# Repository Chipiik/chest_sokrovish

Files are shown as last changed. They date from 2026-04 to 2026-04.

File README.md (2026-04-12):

# 📦 ПРОЕКТ "СУНДУК СОКРОВИЩ" - Биоуправление для коррекции внимания (СДВГ)

## 🎯 Описание проекта

Устройство для тренинга биоуправления, предназначенное для коррекции нарушений внимания (СДВГ) у детей и подростков.

### Задачи устройства:

**Часть 1: Управление крышкой по ЭМГ (мышцы лба)**
- Удерживать ЭМГ ниже порога 3 минуты → крышка открывается (0° → 90°)
- Если ЭМГ выше порога → крышка закрывается в 2 раза быстрее
- Сглаживание сигнала скользящим средним (500 мс)

**Часть 2: Детекция бета-ритма ЭЭГ (13-18 Гц)**
- Если бета-ритм > порога ≥60% времени → зажечь светодиоды ("драгоценные камни")
- Периоды с высоким ЭМГ не засчитываются

---

## 📁 Структура проекта

```
treasure-chest/
├── README.md                    # Этот файл
├── docs/
│   ├── hardware/                # Документация по оборудованию
│   │   └── connection-schema.md # Схема подключения
│   ├── software/                # Документация ПО
│   │   └── bitronics-setup.md   # Настройка Bitronics Lab
│   └── user-guides/             # Руководства пользователя
│       └── quick-start.md       # Быстрый старт
├── src/
│   ├── main/                    # Основная программа с датчиками
│   │   └── treasure_chest.ino
│   └── test/                    # Тестовая программа с эмуляцией
│       └── treasure_chest_test.ino
├── libraries/                   # Библиотеки (при необходимости)
└── !docs/                       # Исходные документы (не изменять)
```

---

## 🔌 Оборудование

### Необходимые компоненты:

| Компонент | Модель | Количество |
|---|---|---|
| Плата Arduino | Arduino Mega 2560 | 1 |
| LED индикатор | Grove LED Bar v1.0 (MY9221) | 1 |
| Сервопривод | FS5103B | 1 |
| Датчик ЭЭГ | Bitronics Lab EEG | 1 |
| Датчик ЭМГ | Bitronics Lab EMG/ECG | 1 |
| Кабели | Grove/Jumper wires | несколько |

### Требуемые библиотеки Arduino:

1. **Grove_LED_Bar** (Seeed Studio) - установка через Library Manager
2. **Servo** (встроена в Arduino IDE)
3. **arduinoFFT** (Enrique Condes) - только для основной версии

---

## 🚀 Быстрый старт

### Вариант 1: Тестирование БЕЗ датчиков (рекомендуется!)

1. **Подключите:**
   - Grove LED Bar к пинам 2, 3
   - Сервопривод к пину 9
   - Arduino к компьютеру через USB

2. **Загрузите:** `src/test/treasure_chest_test.ino`

3. **Откройте Serial Monitor** (115200 бод)

4. **Введите команды:**
   ```
   HELP         ← Получить справку
   AUTO         ← Автоматический режим
   STATUS       ← Показать статус
   SUCCESS      ← Симуляция успеха
   FAIL_EMG     ← Провал по мышцам
   FAIL_EEG     ← Провал по ЭЭГ
   RESET        ← Перезапустить
   ```

### Вариант 2: Работа с реальными датчиками

1. **Подключите все компоненты** по схеме в `docs/hardware/connection-schema.md`

2. **Разместите электроды:**
   - **ЭМГ:** над левой и правой бровью (2 см выше)
   - **ЭЭГ:** Fpz (над переносицей) + за ухом (референт)

3. **Загрузите:** `src/main/treasure_chest.ino`

4. **Откройте Bitronics Lab** или Serial Monitor (112500 бод)

5. **Нажмите RESET** на Arduino

6. **Пройдите калибровку** (30 секунд):
   - Сидите спокойно
   - Лицо расслаблено
   - Глаза открыты

7. **Выполните тренинг** (3 минуты):
   - Расслабьте лоб → крышка открывается
   - Решайте арифметические задачи → бета-ритм растёт

---

## 📊 Критерии успеха

| Условие | Требование | Индикация |
|---|---|---|
| **Крышка** | Открыта ≥54° (60% от 90°) | LED Bar показывает угол |
| **Бета-ритм** | > порога ≥60% времени | Зелёные светодиоды |
| **Общий успех** | Оба условия выполнены | Все светодиоды горят, зелёные мигают 5 раз |
| **Неудача** | Хотя бы одно не выполнено | Красные светодиоды мигают 3 раза |

---

## ⚙️ Настройка параметров

В начале кода можно изменить:

```cpp
// Время тренинга
const unsigned long TIME_TRAINING = 180000; // 3 минуты

// Коэффициенты порогов (1.2 = легче, 1.5 = сложнее)
const float EMG_THRESHOLD_K = 1.3;
const float BETA_THRESHOLD_K = 0.7;

// Процент успеха для бета-ритма
const float BETA_SUCCESS_RATIO = 0.6; // 60%

// Диапазон бета-ритма
const float BETA_FREQ_LOW = 13.0;    // Подростки: 13-18 Гц
const float BETA_FREQ_HIGH = 18.0;
// const float BETA_FREQ_LOW = 12.0;  // Дети: 12-15 Гц

// Скорости серво
const float LID_SPEED_OPEN = 0.15;   // Медленное открытие
const float LID_SPEED_CLOSE = 0.30;  // Быстрое закрытие (×2)
```

---

## 🔋 Автономная работа

**Устройство может работать без компьютера!**

### Что нужно:
- Power Bank 5V 2A (или батарейный отсек 4xAA)
- Подключить к USB порту Arduino или к Vin+GND

### Как работает:
1. Загрузите `src/main/treasure_chest.ino`
2. Подключите все датчики
3. Подайте питание от Power Bank
4. Нажмите RESET
5. Устройство автоматически проведёт калибровку и тренинг

### Индикация результата:
- ✅ **УСПЕХ:** Все 10 светодиодов горят, зелёные мигают 5 раз
- ❌ **НЕУДАЧА:** Красные светодиоды мигают 3 раза

---

## 🐛 Диагностика проблем

| Проблема | Решение |
|---|---|
| Серво дёргается | Отдельное питание 5V 1A+, увеличить SERVO_INTERVAL до 300 |
| Крышка не открывается | Уменьшить EMG_THRESHOLD_K до 1.2, проверить контакт электродов |
| LED Bar не светится | Проверить подключение D1→2, D2→3, установить библиотеку |
| Шум на сигналах | Обезжирить кожу, использовать гель, проверить заземление |
| Всегда неудача | Провести тренировочные сеансы, уменьшить пороги |

---

## ⚡ Техника безопасности

1. ⚠️ **Не подключайте датчики к сети 220V!**
2. ⚠️ **Используйте только питание 5V от USB или батареек**
3. ⚠️ **Проверьте изоляцию проводов перед использованием**
4. ⚠️ **Не используйте на людях с эпилепсией без консультации врача**
5. ⚠️ **При дискомфорте немедленно прекратите сеанс**

---

## 📚 Дополнительная документация

Подробная информация доступна в папке `docs/`:

- `docs/hardware/connection-schema.md` - Подробная схема подключения
- `docs/software/bitronics-setup.md` - Настройка Bitronics Lab
- `docs/user-guides/quick-start.md` - Пошаговое руководство для начинающих

Исходные документы в папке `!docs/` (не изменять):
- Инженерная книга
- Паспорт устройства
- Руководство пользователя BiTronics

---

## 👥 Авторы

Проект разработан для конкурса инженерных книг.

**Лицензия:** Образовательный проект

---

**УДАЧИ В РЕАЛИЗАЦИИ ПРОЕКТА! 🎉**

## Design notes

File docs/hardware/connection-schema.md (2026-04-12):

# 🔌 Схема подключения оборудования

## Общий вид системы

```
                    ┌─────────────────┐
                    │   ARDUINO MEGA  │
                    │                 │
     ЭМГ датчик ────┤ A1          D2  ├──── Grove LED Bar
     (лоб)          │             D3  │      (10 светодиодов)
                    │             D9  ├──── Сервопривод
     ЭЭГ датчик ────┤ A0              │      (крышка сундука)
     (Fpz/Fz)       │           5V/GND├──── Питание
                    │                 │
     Компьютер ─────┤ USB         GND ├──── Общая земля
                    └─────────────────┘
```

---

## 🔌 Подключение к Arduino Mega

### 1. Grove LED Bar v1.0 (MY9221)

| Провод LED Bar | Цвет провода | Пин Arduino Mega | Примечание |
|---|---|---|---|
| GND | Чёрный | GND | Земля |
| VCC | Красный | 5V | Питание 5В |
| D1 (DIN/DATA)  | Белый | **Digital 2** | Данные |
| D2 (CLK) | Жёлтый | **Digital 3** | Тактирование |

**Важно:** 
- Модуль потребляет ~40mA при всех включенных светодиодах
- Можно питать от 5V Arduino

---

### 2. Сервопривод FS5103B

| Провод серво | Цвет | Пин Arduino Mega | Примечание |
|---|---|---|---|
| GND | Коричневый/Чёрный | GND | Земля |
| VCC | Красный | **5V** | Питание |
| SIGNAL | Оранжевый/Жёлтый | **Digital 9**  | PWM сигнал |

**⚠️ ВНИМАНИЕ:**
- Сервопривод в пиковом режиме потребляет до 500mA!
- При проблемах (дёргания, перезагрузки) используйте **отдельное питание 5V 1A**
- Подключите конденсатор 470-1000 мкФ между VCC и GND серво

**Схема с отдельным питанием:**
```
Power Bank 5V ──┬── VCC серво (красный)
                │
                └── Vin Arduino (если нужно)
                
GND Power Bank ─┬── GND серво (коричневый)
                │
                └── GND Arduino (общая земля!)
```

---

### 3. Датчик ЭМГ/ЭКГ Bitronics Lab

| Пин модуля | Обозначение | Пин Arduino Mega | Примечание |
|---|---|---|---|
| GND (-) | Земля | GND | Чёрный провод |
| VCC (+) | Питание | 5V | Красный провод |
| OUT | Сигнал | **Analog A1** | Белый провод |

**Настройка усиления (Gain):**
- На модуле есть потенциометр для настройки усиления
- Начальное положение: среднее
- Для лба: усилить больше (по часовой стрелке)
- Для бицепса: меньше (против часовой)

---

### 4. Датчик ЭЭГ Bitronics Lab

| Пин модуля | Обозначение | Пин Arduino Mega | Примечание |
|---|---|---|---|
| GND (-) | Земля | GND | Чёрный провод |
| VCC (+) | Питание | 5V | Красный провод |
| OUT | Сигнал | **Analog A0** | Белый провод |

**Настройка:**
- Потенциометр Gain выкрутить ближе к максимуму
- ЭЭГ сигнал очень слабый (микровольты)

---

## 👤 Размещение электродов на теле

### Для ЭМГ (мышцы лба):

**Вариант 1 - Лоб (рекомендуется):**
```
        ┌───────────────┐
        │   Электрод 1  │  ← Над левой бровью (2 см выше)
        │       •       │
        │               │
        │   Электрод 2  │  ← Над правой бровью (2 см выше)
        │       •       │
        │               │
        │   Земля       │  ← На виске или за ухом
        │       •       │
        └───────────────┘
```

**Параметры:**
- Расстояние между электродами: 2-3 см
- Обезжирьте кожу спиртом перед наклеиванием
- Используйте гель для ЭКГ для лучшего контакта

---

### Для ЭЭГ (бета-ритм):

**Система координат 10-20:**
```
        Нос
         ↑
    Fpz ─┼─ Fz ─ Cz ─ Pz ─ Oz
    (•)  │  (•)  (•)  
         │   
    ─────┴───── Уши
         │
      Референт (за ухом)
```

**Вариант 1 - Fpz (монополярно, рекомендуется):**
- Активный электрод: над переносицей (Fpz)
  - Отступите ~10% от переносицы вверх по лбу
- Референтный: за правым или левым ухом (сосцевидный отросток)
- Земля: на лбу справа или слева

**Важно:**
- Зачешите волосы в стороны от места крепления
- Используйте специальный гель для ЭЭГ
- Зафиксируйте электроды шапочкой или повязкой

---

## 📦 Установка библиотек

### В Arduino IDE:

1. Откройте **Arduino IDE**
2. Перейдите: **Скетч → Подключить библиотеку → Управлять библиотеками...**
3. Найдите и установите:

| Библиотека | Автор | Версия | Назначение |
|---|---|---|---|
| `Grove LED Bar` | Seeed Studio | ≥2.0.0 | Управление LED баром |
| `Servo` | Arduino | Встроена | Управление серво |
| `arduinoFFT` | Enrique Condes | ≥1.5.6 | БПФ для ЭЭГ (только для основной версии) |

**Для тестовой версии (`treasure_chest_test.ino`) библиотека arduinoFFT НЕ нужна!**

---

## 📊 Таблица пинов Arduino Mega

| Компонент | Пин | Тип | Направление |
|---|-----|-----|---|
| Grove LED Bar DATA | 2 | Digital | Выход |
| Grove LED Bar CLK | 3 | Digital | Выход |
| Сервопривод SIGNAL | 9 | PWM | Выход |
| Датчик ЭЭГ OUT | A0 | Analog | Вход |
| Датчик ЭМГ OUT | A1 | Analog | Вход |
| Все GND | GND | - | Общий |
| Все VCC | 5V | Power | Питание |

**Свободные пины для расширения:**
- Digital: 4-8, 10-13, 14-53
- Analog: A2-A15

---

## ⚡ Техника безопасности

1. **Не подключайте датчики к сети 220V!**
2. **Используйте только питание 5V от USB или батареек**
3. **Перед надеванием электродов проверьте изоляцию проводов**
4. **Не используйте устройство на людях с эпилепсией без консультации врача**
5. **При появлении дискомфорта немедленно прекратите сеанс**

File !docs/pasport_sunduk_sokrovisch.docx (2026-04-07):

Паспорт проекта

Сундук сокровищ

1. Образовательное учреждение: МАОУ Гимназия №7 «Сибирская»
2. Руководитель: Бабаева Елена Александровна
3. Состав команды и роли участников: Бамбурова Дарья Николаевна – нейротехнолог, программист; Куравкин Степан – конструирование.
4. Технические характеристики и область применения.

Для реализации нам потребовались: датчики юниор ЭЭГ и ЭМГ, резистор, светодиод, макетная плата, Arduino Uno, ноутбук с программным обеспечением Arduino, шаговый двигатель и драйвер к нему, соединительные провода, материалы для сундука(дерево).

Мы разработали устройство доступное и

удобное в использовании для тренировки концентрации внимания.

Оно подойдет людям, у которых присутствуют нарушения концентрации внимания.

5. Стоимость реализации.
6. Фотография проекта (или программа).

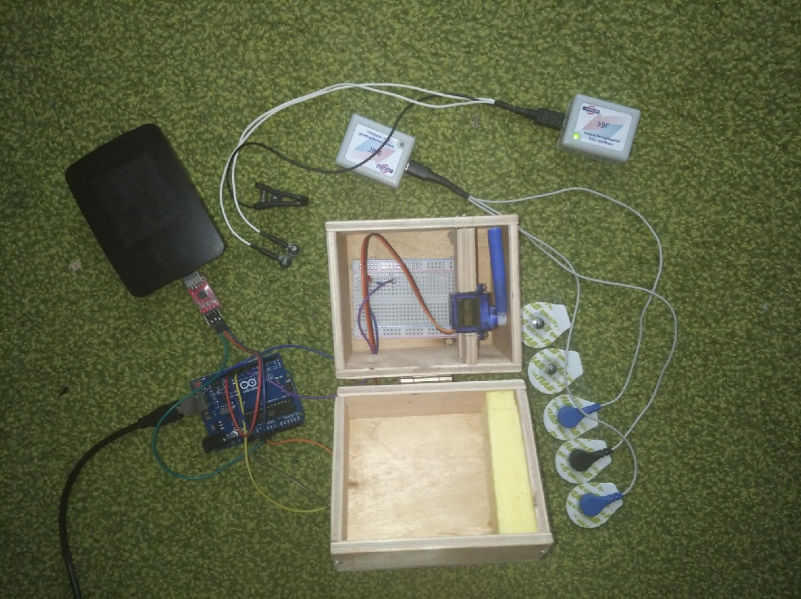
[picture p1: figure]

7. Каталог используемых ресурсов.

Приложение 1. Инженерная книга (отдельным файлом) на 26 страницах.

Приложение 2. Презентация в Power Point (отдельным файлом) на 15 слайдах.

VIII Турнир юных инженеров-исследователей

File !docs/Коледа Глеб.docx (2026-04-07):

Муниципальное автономное общеобразовательное учреждение г. Новосибирска

«Гимназия №7 «Сибирская»

«Умная шкатулка»

Автор:

Коледа Глеб

Руководитель:

Бабаева Елена Александровна

Новосибирск, 2025

Содержание

# Аннотация

Целью моей работы стало создание шкатулки для надежного хранения ценностей, для достижения цели я изучил среду Arduino и разработал конструкцию шкатулки.

Для поиска информации по похожим изобретениям, выполненным на базе Arduino, я использовал ресурсы интернета и профессиональный опыт руководителя.

В ходе работы я написал программу, собрал шкатулку и подключил необходимые приборы. Результатом является работающее устройство, имеющее небольшую стоимость производства. Использование моего продукта актуально для подростков, у которых есть младшие братья или сестры.

# Актуальность

Сейчас многие подростки сталкиваются с ситуацией, когда их младшие братья и сестры берут ценные вещи без спроса, для решения этой проблемы я решил создать уникальную шкатулку, которую невозможно будет открыть без пульта и в которой можно хранить небольшие вещи или копить деньги.

# Цель:

создать умную шкатулку с использованием Arduino .

# Задачи:

1) Изучить аппаратную базу Arduino
2) Изучить программную базу Arduino
3) Освоить работу с ИК-датчиками и сервоприводами
4) Разработать конструкцию и дизайн шкатулки
5) Собрать устройство
6) Провести тесты

Теоретическая часть

Платформа Arduino

Arduino – платформа, с открытым исходным кодом для создания электронных устройств и интерактивных объектов. Состоит из аппаратной и программной части.

Основа аппаратной части – плата с микроконтроллером – маленьким компьютером с собственным процессором, памятью и периферией, на плате также имеются порты ввода/вывода для подключения внешних устройств, разъем питания, USB-порт для загрузки программ и обмена данными с компьютером, кнопка сброса для перезапуска микроконтроллера, индикаторные светодиоды.

Программная часть – Среда разработки Arduino IDE, включает в себя: редактор кода, менеджер библиотек, монитор последовательного порта для обмена данными между платой и компьютером, компилятор для преобразования кода в инструкции для микроконтроллера, загрузчик для передачи программы на плату. Язык программирования представляет собой упрощенную версию С++, адаптированную для микроконтроллеров.

ИК-приемник(IR-receiver) – электронное устройство, обнаруживающее инфракрасное излучение, невидимое для человеческого глаза и декодирующее его в электрические сигналы, передаваемые для интерпретации управляющей схеме устройства

ИК-пульт – электронное устройство, передающее сигналы в инфракрасном диапазоне волн, позволяет управлять электронными устройствами. При нажатии на кнопку, пульт генерирует уникальную последовательность сигналов – код команды, он преобразуется в серию световых импульсов определённой частоты и длительности.

Провода Dupont – компоненты, использующиеся для соединения различных модулей, могут иметь соединения типа «папа-папа», «папа-мама», «мама-мама».

Сервопривод – устройство с электрическим мотором, которое можно повернуть на определенный угол и оставить в этом положении на определенное время. Используется для управления движениями механизмов. Состоит из привода, датчика обратной связи, электронной начинки

Макетная плата – инструмент для быстрого прототипирования электронных схем. Позволяет соединять компоненты схемы без пайки. Состоит из множества отверстий, расположенных в определенном порядке. Горизонтальные линии по краям – силовые шины, обычно использующиеся для подачи питания и земли от Arduino, вертикальные ряды в центральной части связаны между собой и предназначены для установки компонентов.

Кабель ПК-Arduino – это USB кабель для подключения платы к компьютеру, позволяет программировать плату и передавать данные по серийному порту.

Библиотеки Arduino – наборы готовых функций и методов, которые позволяют работать с определенными устройствами, выполняя специфические задачи. Существуют встроенные, дополнительные и зависимые библиотеки.

Светодиод – полупроводниковый прибор, создающий оптическое излучение при пропускании через него электрического тока.

# Практическая часть

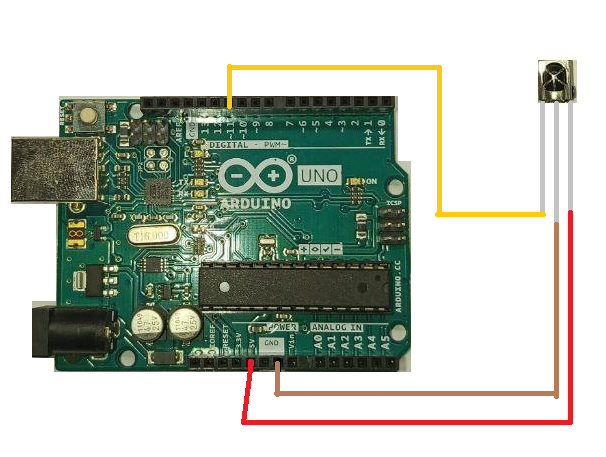
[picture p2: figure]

В своем проекте я использовал плату Arduino UNO, ИК-приемник VS1838B, ИК-пульт, макетную плату, Сервопривод FS5106M, светодиод синий.

## Определение кода

При нажатии на кнопку пульта отправляется код команды, как было сказано выше, для использования пульта необходимо узнать этот код. Для этого воспользуюсь следующей схемой подключения и программой:

Правый контакт приемника подключен к 5V, центральный к GND, левый к пину 11.

#include <IRremote.h>

const int RECV_PIN = 11;

IRrecv irrecv(RECV_PIN);

decode_results results;

void setup() {

Serial.begin(9600);

irrecv.enableIRIn();

}

void loop() {

if (irrecv.decode(&results)) {

Serial.print("Получен код: ");

Serial.println(results.value, HEX);

irrecv.resume(); }

}

В первой стоке загружаю библиотеку IRremote.h (2.6.0) для управления ИК-приемником, далее указываю номер пина, к которому подключен приемник и устанавливаю расшифровку сигнала. В 5-7 строке включаю монитор порта и ИК-приемник. Далее запускаю цикл: если получен сигнал, то в монитор порта выводится результат расшифровки в шестнадцатеричной системе счисления, приемник готовится к получению нового сигнала.

Таким способом определяю код для кнопок «вверх» и «вниз» - FF18E7 и FF4AB5 соответственно.

Основной механизм

После того как я узнал коды кнопок пульта можно приступить к основной части проекта. Собираю следующую схему:

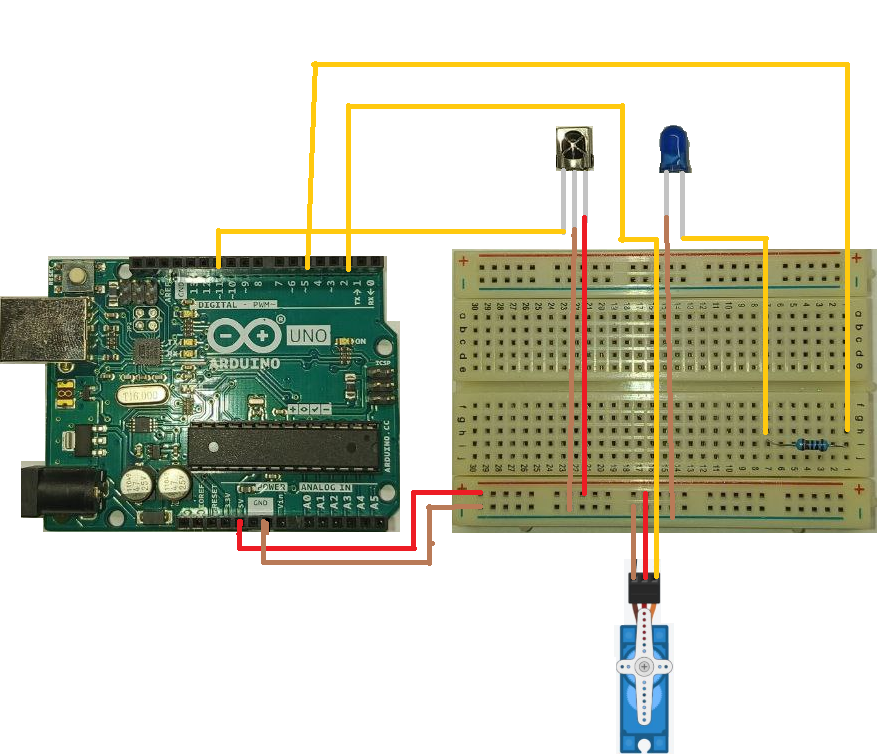
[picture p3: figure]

Приемник подключен к пину 11, светодиод к пину 5, сервомотор к пину 2.

Теперь создаю программу:

#include <IRremote.h>

#include <Servo.h>

#define up 0xFF18E7

#define down 0xFF4AB5

int RECV_PIN = 11;

Servo servo;

IRrecv irrecv(RECV_PIN);

decode_results results;

void setup()

{ Serial.begin(9600);

irrecv.enableIRIn();

servo.attach(2); }

void loop()

{ if (irrecv.decode(&results)) {

Serial.println(results.value, HEX);

irrecv.resume();

}

if (results.value == up)

{ servo.write (90);

digitalWrite(5,HIGH); }

else if (results.value == down) {

servo.write (180);

digitalWrite(5,LOW); }

}

В 1-2 строке подключаю библиотеки для управления сервоприводом и ИК-приемником. В 3-4 строке задаю переменные «up» и «down» через коды пульта.

Далее указываю пин, к которому подключен ИК-приемник, создаю название сервопривода, активирую расшифровку ИК сигнала, монитор порта, ИК-приемник, указываю к какому пину подключен сервопривод.

Использую цикл:

1) если получен сигнал, перевести его в шестнадцатеричную систему, приготовиться к получению следующего сигнала.

2) Если результат декодирования совпадает со значением up, то устанавливается угол сервопривода на 0 градусов и включается светодиод.

3) Если результат декодирования совпадает со значением down, сервопривод устанавливается на 180 градусов и светодиод выключается.

## Установка

В качестве шкатулки использую коробу из фанеры размерами 17х14х13. Крышка утопает внутри коробки так, что ее нельзя открыть руками. Сервомотор размещен на перегородке и при повороте открывает/закрывает крышку. ИК-приемник приклеен к стенке коробки с помощью скотча и принимает сигнал через отверстие. Внутри место для хранения драгоценностей отделено от плат картоном.

# Стоимость

В своем проекте я использовал:

Название компонента | Количество (шт) | Цена (р/шт)* | Стоимость (р)
Плата Arduino UNO | 1 | 634 | 308
ИК-приемник VS1838B | 1 | 38 | 38
ИК-пульт | 1 | 34 | 34
Макетная плата | 1 | 155 | 155
Сервопривод FS5106M | 1 | 252 | 252
Светодиод синий. | 1 | 9 | 9
Коробка | 1 | 449 | 349
Брусок деревянный | 2 | 2,4 | 4,8
Провода «папа-мама» | 5 | 5,3 | 26,3
Провода «папа-папа» | 6 | 3,3 | 19,8
Кабель ПК-Arduino | 1 | 20 | 20
Батарея | 1 | 400 | 400

* - цены взяты с интернет маркетплейсов

Таким образом, стоимость создания моей шкатулки составила 1616 рублей, при стоимости сейфа от 5000 рублей.

# Результат

В ходе проделанной работы я научился работать с устройствами Arduino и создал функционирующую шкатулку, которая открывается с помощью ИК-пульта. Использование моей шкатулки позволяет подросткам спрятать небольшие ценные вещи от младших детей. Стоимость этой шкатулки составляет 1616 рублей

# Ресурсы

Электронные ресурсы:

- [Progoschool - ИК-пульт и Ардуино] - https://progoschool.ru/electronics-for-beginners/ir-remote-control/
- [Arduino+ - Сервопривод Ардуино определение] - https://arduinoplus.ru/arduino-servoprivod/
- [AlexGyvertechnologies - светодиод] - https://alexgyver.ru/lessons/led/
- [Робототехника18 – Как подключить светодиод к Ардуино] - https://роботехника18.рф/светодиод-ардуино/
- [Autodesk Instructables - Controlling Servo Motor Using IR Remote Control] - https://www.instructables.com/Controlling-servo-motor-using-IR-remote-control/

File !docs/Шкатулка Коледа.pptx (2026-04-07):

## Проект "Умная шкатулка"

Выполнил ученик
9Б класса
Коледа Глеб

## Цель и задачи

Цель:
Создать шкатулку с ограниченным доступом
Задачи:
- Изучить аппаратную базу Arduino
- Изучить программную базу Arduino
- Освоить работу с ИК-датчиками и сервоприводами
- Разработать конструкцию и дизайн шкатулки
- Собрать устройство
- Проверить работоспособность устройства

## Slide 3

Среда Arduino

Программная часть

Среда разработки Arduino IDE

Аппаратная часть

Плата
с микроконтроллером

Прочие модули

Редактор кода

Загрузчик

Менеджер библиотек

Монитор порта

## Компоненты

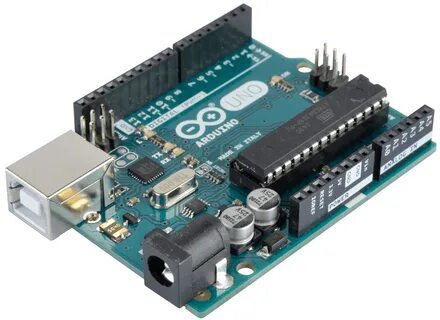
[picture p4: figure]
Изображение выглядит как электроника, Электронный компонент, Компонент схемы, Пассивный компонент цепи Содержимое, созданное искусственным интеллектом, может быть неверным.

Плата с микроконтроллером

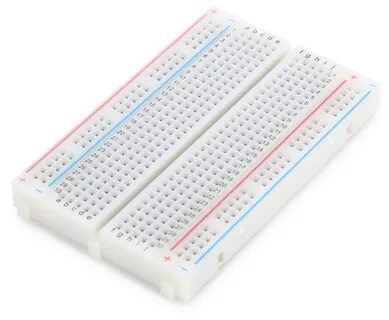
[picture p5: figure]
Изображение выглядит как текст Содержимое, созданное искусственным интеллектом, может быть неверным.
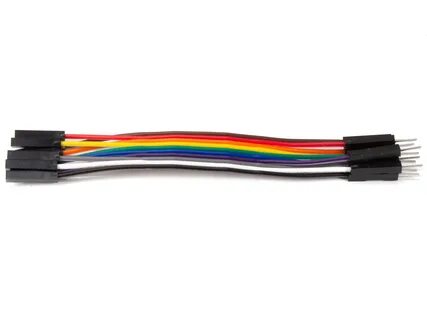
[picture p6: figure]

Макетная плата

Провода "папа-мама"

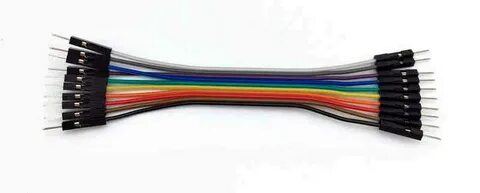
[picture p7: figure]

Провода "папа-папа"

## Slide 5

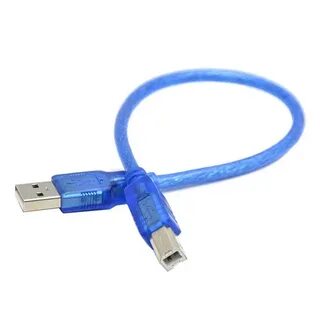
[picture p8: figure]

Кабель ПК-Arduino

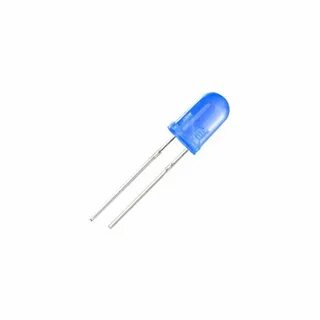
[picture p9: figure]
9 штук, Светодиод 3мм, цв. синий, LED - купить в интернет-магазине по низкой цен

Светодиод

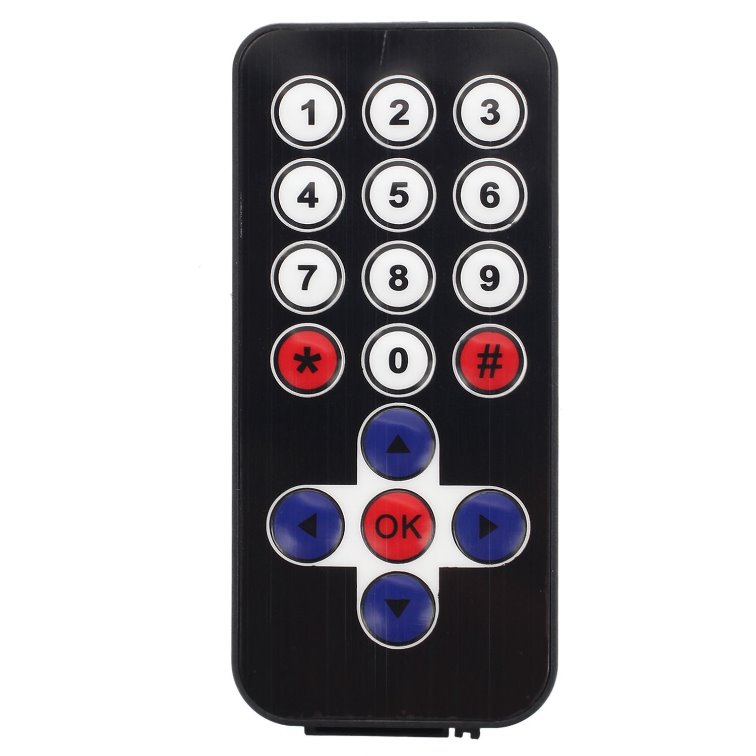
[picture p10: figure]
Picture background

ИК-пульт

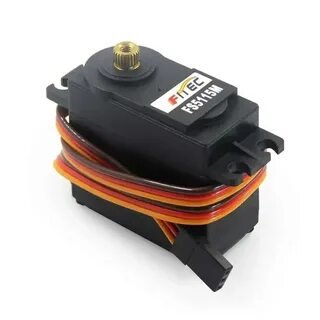
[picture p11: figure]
Серводвигатель Feetech FS5115M 15 кг для робота AliExpress

Сервопривод

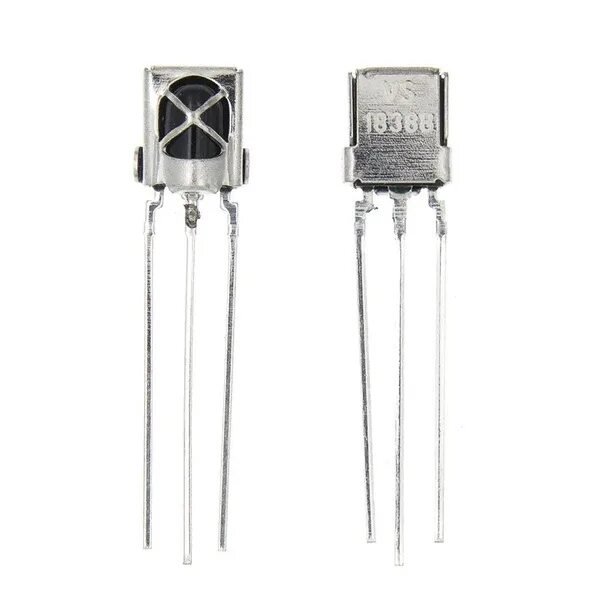
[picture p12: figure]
Picture background

ИК-приемник

## Коды пульта

#include <IRremote.h>

const int RECV_PIN = 11;
IRrecv irrecv(RECV_PIN);
decode_results results;
void setup() {
Serial.begin(9600);
irrecv.enableIRIn(); }
void loop() {
if (irrecv.decode(&results)) {
Serial.print("Получен код: ");
Serial.println(results.value, HEX);
irrecv.resume(); }
}

№ п/п | Кнопка | Код
1 | «вверх» | FF18E7
2 | «вниз» | FF4AB5

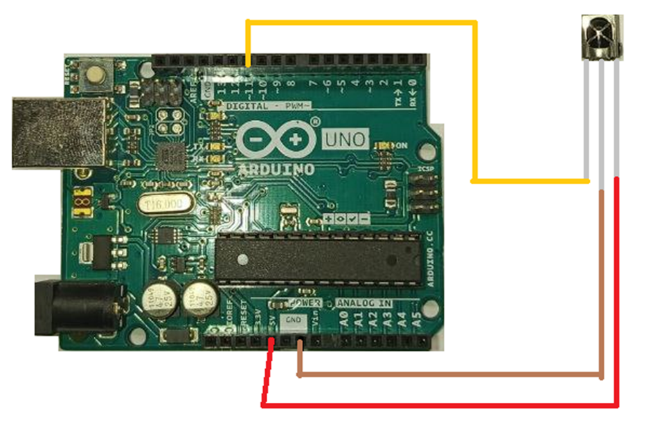
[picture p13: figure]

## Основная часть

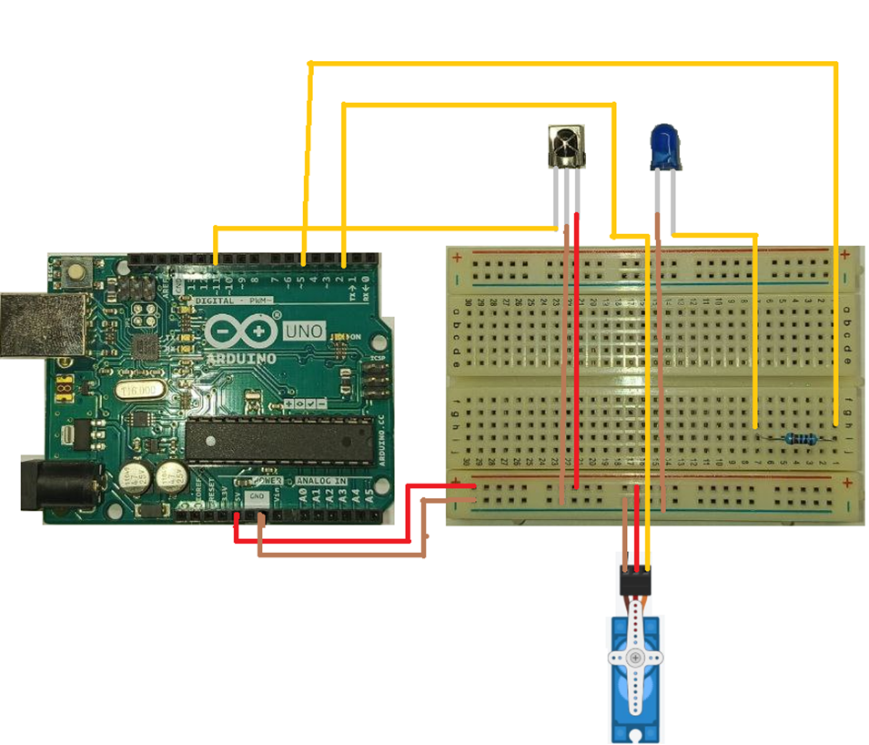
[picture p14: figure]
Изображение выглядит как электроника, Электронный компонент, Компонент схемы, Пассивный компонент цепи Содержимое, созданное искусственным интеллектом, может быть неверным.

#include <IRremote.h>

#include <Servo.h>

#define up 0xFF18E7

#define down 0xFF4AB5

int RECV_PIN = 11;
Servo servo;
IRrecv irrecv(RECV_PIN);
decode_results results; ;
void setup()
{ Serial.begin(9600);
irrecv.enableIRIn();
servo.attach(2); }
void loop()
{ if (irrecv.decode(&results)) {
Serial.println(results.value, HEX);
irrecv.resume();
}
if (results.value == up)
{ servo.write (90);
digitalWrite(5,HIGH); }
else if (results.value == down){
servo.write (180);
digitalWrite(5,LOW); } }

## Устройство шкатулки

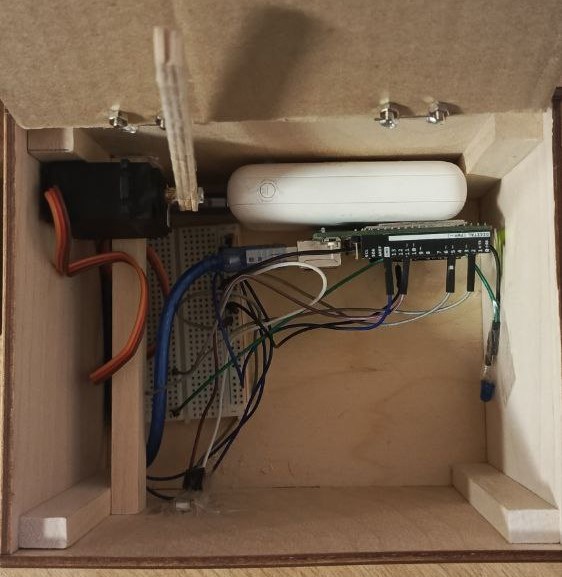
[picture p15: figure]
Изображение выглядит как в помещении, стена, Электрическая проводка, кабель Содержимое, созданное искусственным интеллектом, может быть неверным.
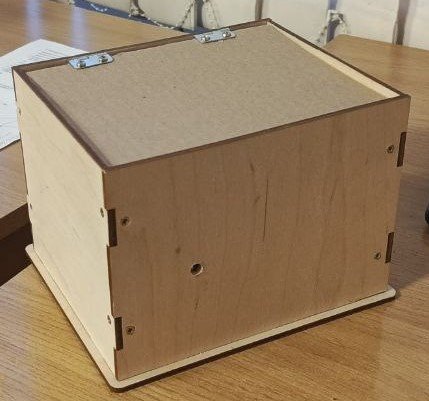
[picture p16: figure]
Изображение выглядит как пол, картон, коробка, в помещении Содержимое, созданное искусственным интеллектом, может быть неверным.

Вид внутри

Вид снаружи

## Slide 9

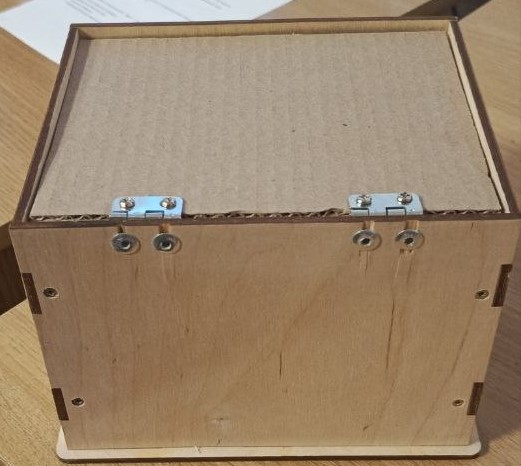
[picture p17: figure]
Изображение выглядит как коробка, контейнер, картон, Упаковочная коробка Содержимое, созданное искусственным интеллектом, может быть неверным.
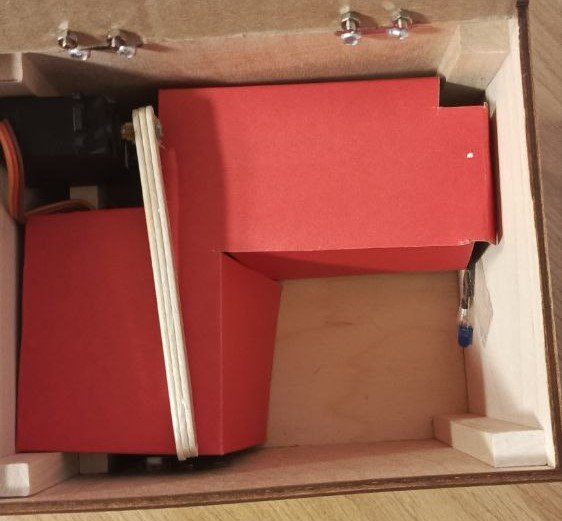
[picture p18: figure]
Изображение выглядит как раковина, в помещении, коробка, стена Содержимое, созданное искусственным интеллектом, может быть неверным.

Вид сзади

Вид внутри с кожухом

## Стоимость проекта

Название компонента | Кол-во (шт) | Цена* (руб/шт) | Стоимость (руб)
Плата Arduino UNO | 1 | 308 | 308
ИК-приемник VS1838B | 1 | 38 | 38
ИК-пульт | 1 | 34 | 34
Макетная плата | 1 | 155 | 155
Сервопривод FS5106M | 1 | 252 | 252
Светодиод синий. | 1 | 9 | 9
Коробка | 1 | 347 | 347
Брусок деревянный | 1 | 2,4 | 2,4
Провода «папа-мама» | 5 | 5,3 | 26,3
Провода «папа-папа» | 6 | 3,3 | 19,8
Кабель ПК-Arduino | 1 | 20 | 20
Картонный лист | 1 | 2 | 2
Батарея | 1 | 400 | 400
ИТОГО | | | 1613

*-цены по данным маркетплейсов

## Заключение

В результате выполнения работы создана функционирующая шкатулка, которая открывается с помощью ИК-пульта. Стоимость шкатулки - 1613 рублей. Эта шкатулка может быть использована подростками для хранения небольших ценных вещей.
Также были приобретены следующие компетенции:
- Навыки сборки электрической схемы
- Навыки поиска и изучения информации о платформе Arduino
- Навыки программирования микроконтроллера Arduino
- Навыки обработки дерева
- Умение оформления отчета

## Проект "Умная шкатулка"

Выполнил ученик
9Б класса
Коледа Глеб

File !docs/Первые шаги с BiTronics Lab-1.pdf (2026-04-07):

# Изучай и создавай устройства в области биосигналов!

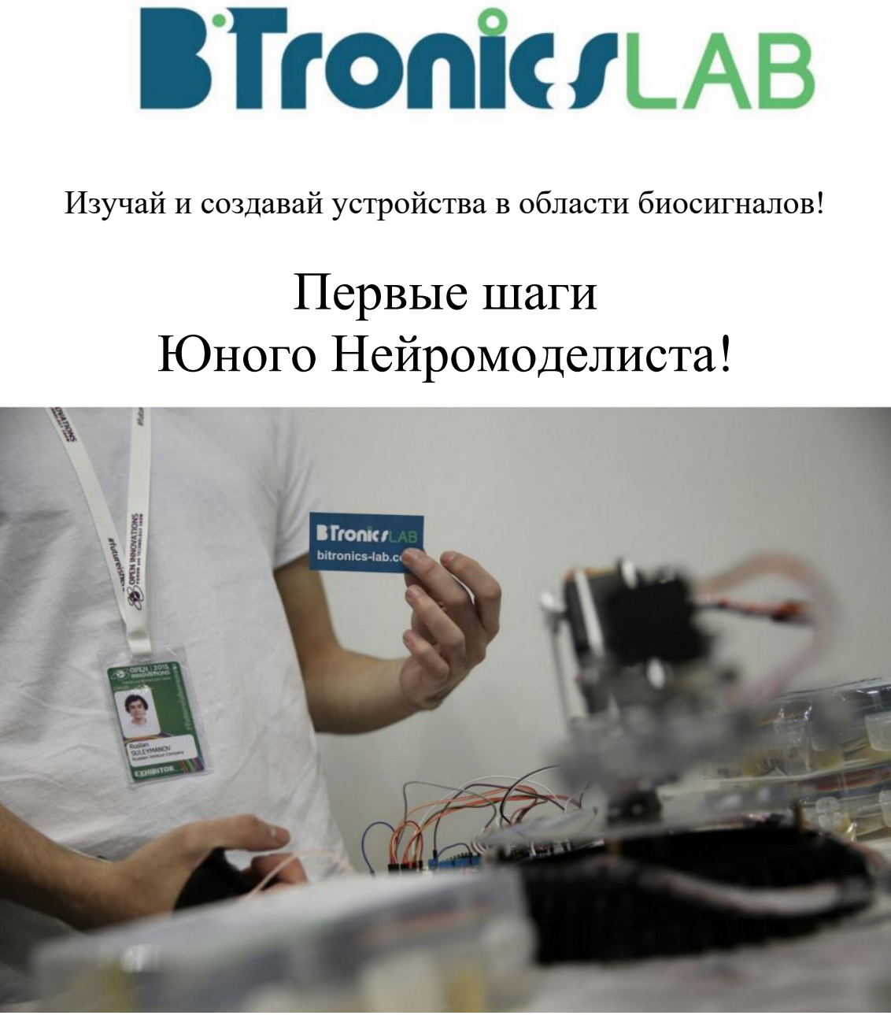
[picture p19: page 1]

# Первые шаги Юного Нейромоделиста!

www.bitronicslab.com

Привет!

Хотите сделать своими руками детектор лжи, управлять с помощью силы мысли и создавать устройства в области био- и нейро- сигналов человека?

Если ответ на эти вопросы «да», то вы сделали совершенно правильный выбор. Набор-конструктор «Юный Нейромоделист» BiTronicsLAB – это то, что позволит вам проявить и развить техническую изобретательность в области био- и нейро- сигналов человека уже в ближайшие дни!

Наша команда состоит из студентов и аспирантов МФТИ, мы являемся
специалистами | в | области | радиоэлектроники, | кибернетики | и
физиологии. Все эти направления мы решили сделать для вас более доступными.

В ваших руках находится Первый в Мире набор-конструктор «Юный Нейромоделист» BiTronicsLAB для изучения области био- и нейро-сигналов человека.

Итак, что же из себя представляет наша платформа? Мы разработали следующий уникальный набор сенсоров и модулей:

- Модуль ЭМГ (модуль электромиографии) - сенсор мышечной активности, регистрирующий разность потенциалов, возникающую в мышце при ее сокращении или расслаблении
- Модуль ЭЭГ (модуль электроэнцефалографии) – сенсор мозговой активности, фиксирующий сигналы, поступающие с коры головного мозга
- Модуль пульса - простой и готовый к использованию и встраиванию модуль, фиксирующий пульс человека
- Модуль КГР (модуль кожной-гальванической реакции) - сенсор кожно-гальванической реакции, уникальный функционирующий модуль, который позволит создать вам свой собственный детектор лжи. А вы уверены в своих друзьях? :)
- Модуль ЭКГ (сенсор электрокардиографии) – сенсор сердечной активности, позволяющий вести регистрацию кардиосигнала. Если вы давно хотели понять, как устроена процедура ЭКГ в вашей поликлинике, мы откроем вам эту тайну!

Это было первое краткое знакомство с нашим конструктором. Далее мы подробно расскажем, как работать с модулями набора-конструктора «Юный Нейромоделист» BiTronics Lab

### 1. Подключение и настройка Arduino

Прежде чем начать работу с биосигналами человека, мы предлагаем ознакомиться

с платой Arduino. Под маркой Arduino выпускаются различные платы с

микроконтроллером – UNO, Leonardo, Nano и другие. Программирование данных

плат осуществляется с помощью специальной программной оболочки (Arduino IDE).

### 1.1 Установка Arduino IDE

Скачайте | программную | оболочку | Arduino | по | адресу

www.arduino.cc/en/Main/Software и установите её.

### 1.2 Установка драйверов

Подключите плату Arduino к компьютеру через USB-кабель. Если плата была

подключена правильно, на ней должны загореться светодиоды. Если установка

драйверов не началась автоматически, откройте Диспетчер устройств (Пуск –

Панель управления – Диспетчер устройств). Найдите плату Arduino. Кликните по

ней правой кнопкой мыши и выберите Обновить драйверы… В открывшемся окне

выберите пункт Выполнить поиск драйверов на этом компьютере. Нажмите на

кнопку Обзор. В открывшемся окне вам необходимо указать папку Drivers,

находящуюся в папке с установленной Arduino IDE. Расположение данной папки

можно узнать, кликнув правой кнопкой мыши на ярлыке Arduino, созданном после

установки Arduino IDE, и выбрав пункт Расположение файла. После выбора папки

Drivers нажмите OK, затем – Далее. После завершения установки нажмите

Закрыть.

Дополнительную информацию об установке Arduino IDE и драйверов можно

получить по ссылке www.arduino.cc/en/Guide/HomePage (на английском) либо по

www.arduino.ru/Guide/Windows (справка на русском языке).

### 1.3 Загрузка скетчей

Скетч – это программа, написанная в среде Arduino. Создание и загрузка скетчей

на плату Arduino осуществляются с помощью Arduino IDE. По умолчанию папка

Arduino со скетчами и библиотеками находится в папке Мои документы. Файл

скетча имеет расширение .ino. Он должен находиться в одноимённой папке. Если это не так, то при попытке его открыть Arduino IDE сообщит об этом и предложит

переместить скетч в папку с тем же названием.

Для работы с биосигналами мы используем библиотеку TimerOne, которую можно

скачать по ссылке www.bitronicslab.com/guide и сохранить в папке Мои

документы\Arduino\libraries.

Рассмотрим | загрузку | программ | на | плату | Arduino | на | примере | скетча

TwoSensors.ino, расположенного по адресу www.bitronicslab.com/guide. Данный

скетч каждые 3 мс считывает данные с аналогового входа платы A0, а каждые 30

мс - с А1 и отправляет их на компьютер.

- Сохраните скетч в папке Мои документы\Arduino.
- Запустите программу Arduino.
- Нажмите Файл – Открыть…, выберите скетч | TwoSensors.ino | и нажмите

Открыть.

- В появившемся окне Перемещение нажмите OK (данное окно откроется

только в случае, если скетч находится в папке, название которой отличается

от названия скетча).

- В разделе Инструменты – Плата выберите название, соответствующее

плате, подключенной к компьютеру.

- В разделе Инструменты – Порт выберите порт, к которому подключена

ваша плата.

- Нажмите | кнопку | Загрузка

Внимание! Не отключайте плату от компьютера до завершения загрузки.

### 2. Считывание биосигналов

В конструктор-набор «Юный Нейромоделист» BiTronics Lab входят модули для

электромиографии, | электрокардиографии, | фотоплетизмографии,

электроэнцефалографии и считывания кожно-гальванической реакции. Из данного

раздела вы узнаете, как подключить данные модули к плате Arduino и

визуализировать биосигналы.

Все модули, за исключения модуля Пульс, имеют две группы контактов: к одной из

них подключаются электроды, другая используется для питания модуля (контакты

+ и -) и передачи усиленного сигнала (OUT). Амплитуду сигнала на модулях

EMG/ECG, EEG, GSR можно менять с помощью регулятора Gain | .

Внимание! Для предотвращения порчи оборудования, подключение модулей

необходимо производить при отключённой от питания плате Arduino.

### 2.1 Электромиография, электрокардиография

Электромиография — это метод исследования биоэлектрических потенциалов,

возникающих в скелетных мышцах человека и животных при возбуждении

мышечных волокон. Характерная амплитуда считываемых электрических сигналов,

возникающих в мышцах, составляет порядка нескольких милливольт. Считанный и

обработанный | сигнал | можно | использовать | для | управления | различными

устройствами, а также для анализа биомеханики человека.

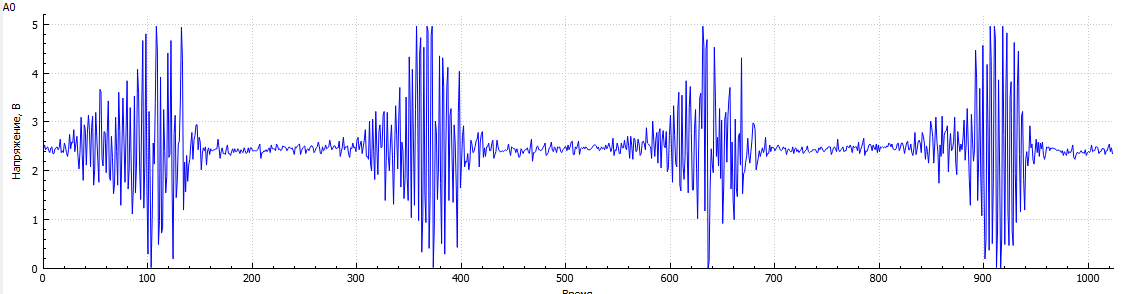
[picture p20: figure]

Вид сигнала с бицепса, полученного с помощью модуля ЭМГ/ЭКГ. Участки с высокой амплитудой

соответствуют моменту напряжение мышцы.

Электрокардиогра́фия - это методика регистрации и исследования

электрических | сигналов, | образующихся | при | работе | сердца.

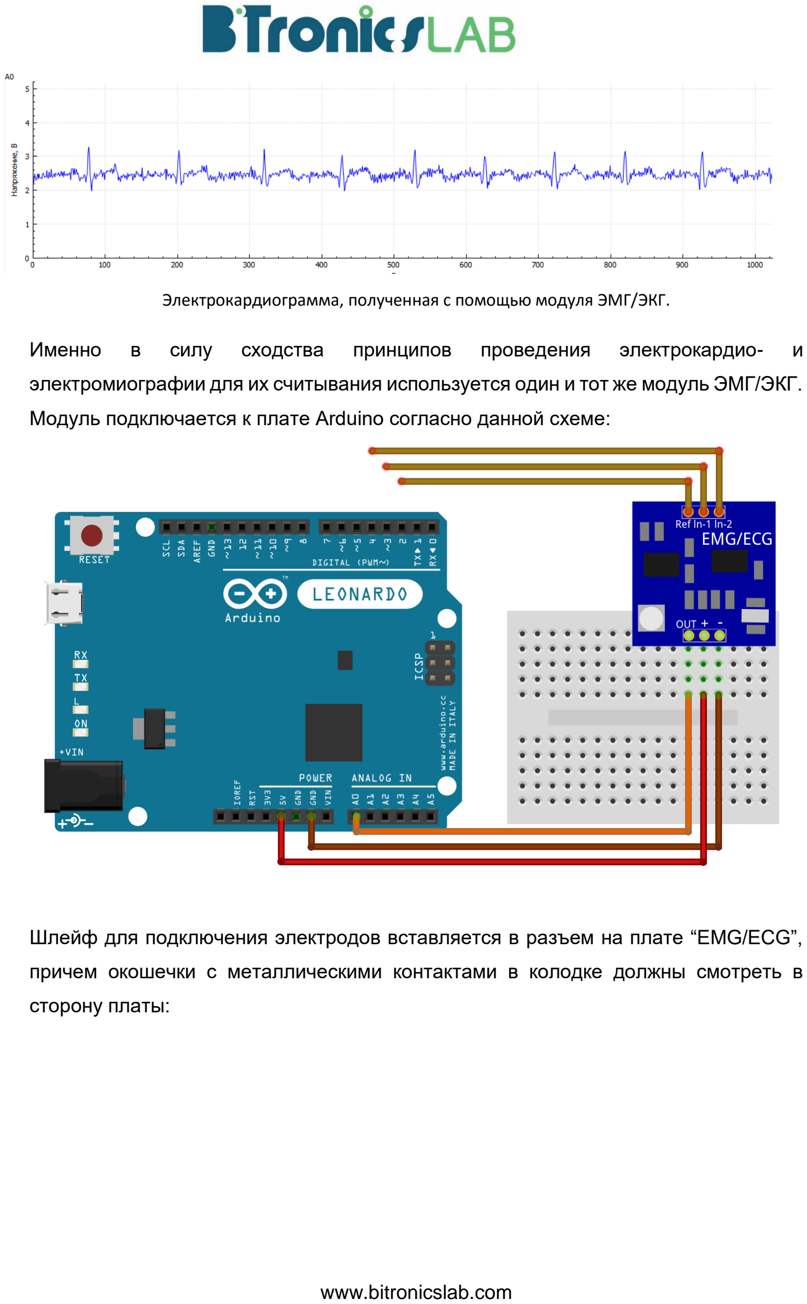
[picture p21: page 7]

Электрокардиограмма, полученная с помощью модуля ЭМГ/ЭКГ.

Именно | в | силу | сходства | принципов | проведения | электрокардио- | и

электромиографии для их считывания используется один и тот же модуль ЭМГ/ЭКГ.

Модуль подключается к плате Arduino согласно данной схеме:

Шлейф для подключения электродов вставляется в разъем на плате “EMG/ECG”,

причем окошечки с металлическими контактами в колодке должны смотреть в

сторону платы:

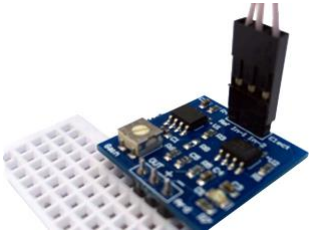
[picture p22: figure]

Это необходимо для корректного подключения референсного электрода в первых

версиях модуля.

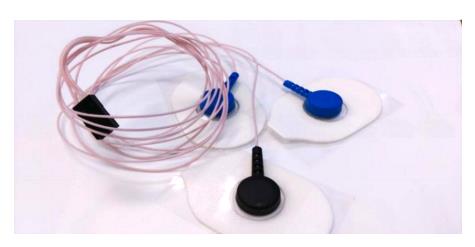
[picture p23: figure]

Электроды для электромио-, электрокардиографии

Для получения электромиограммы необходимо наклеить два электрода на кожу над

мышцей вдоль роста мышечных волокон. Расстояние между центрами электродов

должно быть около 2 сантиметров, при этом электроды могут немного

перехлёстываться. К этим двум электродам необходимо присоединить кнопки

одинакового цвета. Третий электрод необходимо наклеить на локоть или запястье

- к нему нужно подсоединить кнопку черного цвета.

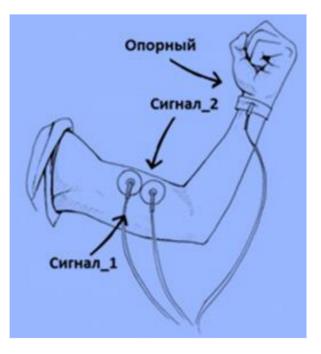
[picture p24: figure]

Схема подключения электродов для считывания ЭМГ-сигнала с бицепса

Для получения электрокардиограммы необходимо разместить сигнальные

электроды в области сердца, а опорный электрод (чёрного цвета) можно приклеить

к локтю, или закрепить на запястье:


Также электрокардиограмму можно получить, наклеив на одно запястье рядом

сигнальный электрод и опорный, на другое – второй сигнальный электрод. В случае

если картина электрокардиограммы выглядит «перевёрнутой» - необходимо

поменять сигнальные электроды местами.


### 2.2 Фотоплетизмография

Фотоплетизмография — это метод исследования динамики кровенаполнения

сосудов, основанный на измерении оптической плотности. Другими словами, в

зависимости от количества крови в капиллярах, на которые светят, изменяется

количество отражаемого ими света. Наблюдение за интенсивностью отраженного

света и позволяет измерить частоту сердечных сокращений человека.

Вид сигнала с модуля Pulse

Считывание фотоплетизмограммы осуществляется с помощью модуля Pulse.

Модуль подключается к плате Arduino согласно данной схеме:

Фотоплетизмограмму можно получить, приложив фотодиод и светодиоды модуля к

подушечке пальца, либо к запястью.


### 2.3 Кожно-гальваническая реакция

Кожно-гальваническая реакция (КГР, GSR) — это биоэлектрическая реакция,

регистрируемая с поверхности кожи. Величина сопротивления поверхности кожи

используется как показатель функционального состояния центральной нервной

системы. В расслабленном состоянии, например, во сне, сопротивление кожи

повышается, а при стрессе — понижается. В том числе, на данный показатель

влияет уровень напряжения, тревоги, усиление мыслительной деятельности. Это

изменение и позволяет зарегистрировать модуль КГР.


Вид сигнала с сенсора кожно-гальванической реакции

КГР можно регистрировать с любого участка кожи, но лучше всего — с пальцев,

кистей рук, подошв ног. Электроды из набора позволяют получить сигнал с пальцев

рук.

Модуль КГР (GSR) подключается к Arduino согласно данной схеме:


Можно заметить, что, в отличие от других модулей, сигнал GSR идёт на аналоговый

вход A1, а не на A0. В разделе Загрузка скетчей предлагалось загрузить скетч,

отправляющий сигнал на компьютер с входа A0 каждые 3 мс, а с входа A1 – каждые

30 мс, и в приведённых схемах подключения предполагается, что на плату Arduino

загружен данный скетч.

Шлейф для подключения электродов вставляется в разъем на плате GSR.

Электроды надеваются на пальцы одной руки (например, на указательный и

средний) таким образом, чтобы металлическая часть плотно прилегала к

подушечкам пальцев.


Модуль КГР с электродами для снятия реакции с пальцев


### 2.4 Электроэнцефалография

Электроэнцефалография (ЭЭГ) изучает суммарную электрическую активность

мозга. ЭЭГ позволяет исследовать реакцию мозга на действие раздражителей,

исследовать ритмы электрической активности головного мозга.

Вид сигнала с модуля ЭЭГ

Считывание сигнала ЭЭГ осуществляется с помощью модуля EEG. Помимо

регулятора Gain, EEG имеет регулятор Noise, предназначенный для регулировки

подавления шумов. Модуль подключается к плате Arduino согласно следующей

схеме:

Для снятия электроэнцефалограммы используется ремень с тремя электродами:

двумя сигнальными и одним опорным. Два сигнальных электрода имеют зубцы,

предназначенные для лучшего контакта с кожей. Они размещаются на затылке на

уровне верхней части ушной раковины. Опорный электрод с присоединённой к нему

чёрной кнопкой размещается за ушной раковиной.


Размещение электродов для считывания ЭЭГ-сигнала

### 3. Изучение биосигналов в программе Bitronics Lab

После подключения модуля к плате Arduino и подключения соответствующих

электродов к телу человека, можно приступить к изучению биосигналов. Для их

визуализации мы предлагаем использовать программу Bitronics Lab. Скетч,

который мы предлагали загрузить на плату в предыдущем разделе, считывает

сигналы с аналоговых входов A0 (каждые 3 мс) и A1 (каждые 30 мс) и отправляет

данные на компьютер. Программа Bitronics Lab позволяет визуализировать эти

данные, записать их, увидеть спектр сигнала. Актуальную версию программы-

визуализатора можно скачать по ссылке www.bitronicslab.com/guide.

Для визуализации сигнала подключите плату Arduino к компьютеру через USB

кабель. Запустите программу Bitronics Lab. Окно программы имеет пять вкладок:

Пульс, КГР, ЭМГ, ЭКГ и Визуализатор. По умолчанию откроется последняя.


Окно программы Bitronics Lab, открытое на вкладке Визуализатор

В данном окне можно увидеть данные, поступающие с четырёх каналов

одновременно. По оси абсцисс откладывается время, по оси ординат – значение

напряжения от 0 до 5 В на данном канале.

Необходимо | нажать | кнопку | Настройки

Окно настроек программы Bitronics Lab

В открывшемся окне в списке Выбор порта необходимо выбрать порт, к которому

подключена плата Arduino. При правильном выборе в строке Описание вы увидите

название вашей платы Arduino. В списке Скорость передачи необходимо выбрать скорость 112500 (если, конечно, вы не меняли скорость передачи в скетче

TwoSensors.ino). В списке КГР выберете порт A1, так как именно с него

считывается кожно-гальваническая реакция. Далее нажмите Применить.

Для начала считывания сигнала нажмите кнопку Подключить порт ( ).Если вы всё

сделали правильно, должен начать считываться сигнал. При открытии вкладки,

соответствующей подключённому модулю, вы можете увидеть его | спектр.

В программе Bitronics Lab имеются триггеры для работы со

спектром сигнала, получаемого с модулей EEG и EMG. Они позволяют следить за

амплидудой определённой части спектра и посылать на Arduino сигналы,

зависящие от того, превышает ли амлитуда определённое значение или нет. Для

того чтобы включить триггер, необходимо поставить галочку рядом с одним из

триггеров в правой части программы (триггеры имеются только на вкладках ЭЭГ и

ЭМГ).


Триггеры в программе Bitronics Lab

После включения триггера, на графике спектра появится прямоугольная область

соответствующего цвета. Параметр Порог отвечает за высоту области, параметр

Частота - за положение середины, а Ширина окна - за полуширину прямоугольной

области. Первое поле Обратный сигнал отвечает за сообщение, отправляемое на

контроллер в случае, если амплитуда какой-либо из составляющих спектра,

попадающих в область триггера, превышает порог. Сообщение во втором поле

отправляется на Arduino в противном случае. Максимальная длина сообщения - 7

символов.

Заключение

Дорогие друзья, на этом мы заканчиваем краткий рассказ о том, как запустить наш

набор и сделать первые шаги! В самое ближайшее время мы расскажем вам о том,

что интересного собирают и как используют набор-конструктор BiTronics ваши

коллеги по всему Миру.

Мы любим и вкладываем душу в нашу платформу, С уважением,
Команда BiTronicsLab

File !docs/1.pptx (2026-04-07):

## Электромиографическое исследование состояния мышц(Кто сильнее)

## Актуальность

- В современном обществе все больше подростков страдает от недостатка физической активности, проводя много времени перед экранами и ведя сидячий образ жизни. Это может приводить к слабости мышц, снижению выносливости и развитию различных компликаций. Исследование состояния мышц подростков поможет выделить группы риска и разработать программы физической активности, способствующие оптимальному развитию мышц и улучшению общего физического состояния.

## Цели:

- 1.Ознакомиться с программой "Бослаб" и изучить ее основные возможности
- 2. Провести тестирование программы для определения ее эффективности.
- 3. Провести исследование методом электромиографии (ЭМГ) с целью получить дополнительные данные и анализировать результаты.
- 4.Предоставить рекомендации по занятиям спортом для людей, у которых уровень ЭМГ ниже среднего, чтобы помочь им достичь лучших результатов.

## Гипотеза

- Предполагается, что изучение программы «Бослаб», проведение испытаний программы, исследование ЭМГ и предоставление рекомендаций по занятию спортом людям с нижним уровнем ЭМГ будут способствовать уменьшению времяпровождения в сидячем образе жизни, повышению комфорта и эффективности тренировок, а также улучшению результатов физической активности у пользователей

## Теоретическая часть

- Строение мышц у подростков:
- Мышцы являются основными двигательными органами организма и состоят из мышечных волокон. Мышечные волокна объединяются в пучки и связываются с сухожилиями и костями, обеспечивая движение и поддержку тела. Существует три типа мышц - скелетные, гладкие и сердечные. В данном исследовании мы сосредоточимся на скелетных мышцах, которые отвечают за движение тела. Скелетные мышцы состоят из множества мышечных волокон, которые, в свою очередь, состоят из миофибрилл. Миофибриллы состоят из актиновых и миозиновых филаментов, которые образуют саркомеры - основные сократительные единицы мышц.


## Теоретическая часть

- Принципы работы электромиографии:
- Электромиография - это метод исследования, который позволяет регистрировать электрическую активность мышц. Для проведения электромиографического исследования используются электроды, которые размещаются на коже над мышцами. Электроды регистрируют электрическую активность мышц в виде сигнала, который затем анализируется. При сокращении мышц происходит электрическая активация мышечных волокон, что приводит к изменению потенциала на поверхности кожи. Электроды регистрируют эти электрические сигналы, которые затем анализируются для оценки активности мышц.
- Активность мышц у подростков:
- В подростковом возрасте происходит интенсивное развитие мышц, связанное с ростом и физической активностью. Силовые тренировки имеют особое значение для развития мышц у подростков. Исследования показывают, что силовые тренировки способствуют укреплению и развитию мышц, повышают их силу и выносливость.


## Применение

- 1) Диагностика мышечных заболеваний:
- Электромиография позволяет оценить электрическую активность мышц и выявить нарушения в их функционировании. Это может помочь в диагностике различных мышечных заболеваний, таких как мышечная дистрофия, миастения гравис, паралич Белла и другие.
- 2)Оценка мышечного развития:
- Электромиография может быть использована для измерения силы и активности мышц у подростков. Это помогает оценить уровень мышечного развития и выявить возможные дисбалансы или слабые зоны, которые могут быть скорректированы с помощью соответствующих упражнений и тренировок.
- 3)Исследование физиологии мышц:
- Электромиография также может быть использована для изучения физиологии мышц у подростков. Она позволяет измерить активность мышц в различных условиях, например, во время физической активности, покоя или реабилитации после травмы. Это помогает ученым лучше понять, как мышцы функционируют и адаптируются к различным стимулам.
- 4) Оценка эффективности лечения:
- Электромиография может быть полезна для оценки эффективности лечения мышечных заболеваний у подростков. Она позволяет отслеживать изменения в активности мышц и силе после применения определенных методов лечения, таких как физиотерапия, массаж или лекарственная терапия.
- 5)Оптимизация физической активности:
- Электромиография может помочь оптимизировать физическую активность у подростков. Измерение активности мышц во время различных упражнений и тренировок позволяет определить наиболее эффективные методы тренировки и управления нагрузкой для достижения оптимальных результатов.

## Теоретическая часть

- 1.3. Программно-аппаратный комплекс Бослаб
- Программный комплекс Бослаб – программа, использующаяся для лечения и реабилитации большого количества заболеваний методом биоуправления.
- Комплекс состоит из:
- Программы «Бослаб Юниор».
- USB-адаптера беспроводной связи.
- Датчиков ЭМГ и ЭЭГ.
- Беспроводных модулей ЭЭГ и ЭМГ.
- Подключение датчиков:
- Подключение Bluetooth адаптера в порт компьютера.
- Подключить к беспроводным модулям соответствующие датчики.
- Наложить электроды датчиков на пациента при помощи одноразовых поверхностных электродов(ЭМГ) или электропроводной пасты(ЭЭГ)
- После этого можно приступать к использовании программы Бослаб:
- Запускаем программу, создаем нового пациента, затем создаем курс, в котором создаем новый сеанс. После во вкладке сессий указываем нужный нам шаблон сеанса. После перечисленных действий нажимаем на кнопку Старт, после чего наблюдаем мониторинг напряжения мышц.

## Проведение исследования

- Мы выбрали 5 подростков среднего телосложения, роста и веса. Это позволит нам получить показательность данных и обобщить результаты на более широкую группу подростков.

## Показания первого испытуемого


## Показания второго испытуемого


## Показания третьего испытуемого


## Показания четвертого испытуемого


## Показания пятого испытуемого


## Итоги

- Полученные результаты показали, что у первого, третьего и четвертого подростка активность мышц была примерно одинаковой. Это может указывать на схожую физическую подготовку и уровень тренированности этих подростков. У одного из подростков наблюдалось немного более высокое значение активности мышц. Возможно, это связано с более интенсивной физической активностью или с особенностями его мышц.
- Однако, у одного из подростков было зафиксировано очень низкое значение активности мышц. Это может указывать на недостаточную развитость или слабость мышц у данного подростка. Возможно, это связано с недостатком физической активности или с какими-то особенностями его организма.
- После проведения и анализа испытания мы узнали, что у одного испытуемого значение порога меньше среднего(значение),поэтому мы предоставили рекомендации к занятию спортом.

## Рекомендации для 3-го испытуемого

- Рекомендуется проконсультироваться с врачом или тренером. Это поможет разработать индивидуальную программу тренировок и учитывать особенности его физического развития.Важно включить в программу тренировок разнообразные упражнения, которые развивают различные группы мышц. Это поможет укрепить слабые мышцы и сбалансировать их развитие. При начале тренировок рекомендуется выбирать умеренную интенсивность, чтобы избежать перенапряжения слабых мышц и возможных травм. Постепенно увеличивайте интенсивность тренировок по мере укрепления мышц. Также важно поддерживать регулярность тренировок, чтобы достичь прогресса. Рекомендуется тренироваться не менее 3-4 раз в неделю, уделяя внимание как укреплению слабых мышц, так и общей физической активности.

## Вывод

- Программа "Бослаб" является мощным инструментом для тренировки и анализа физических возможностей, ознакомившись с основными возможностями программы и уже с помощью нее мы смогли провести электромиографическое исследование, которое прошло успешно. Таким образом, наш проект позволил нам ознакомиться с программой "Бослаб", провести тестирование ее эффективности, использовать метод электромиографии для получения дополнительных данных и предоставить рекомендации по занятиям спортом для участника с нижним уровнем ЭМГ

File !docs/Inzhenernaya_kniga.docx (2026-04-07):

Муниципальное автономное общеобразовательное учреждение

города Новосибирска

«Гимназия №7 «Сибирская»

Инженерная книга

«Сундук сокровищ»

Авторы работы:

Воробьев Матвей

Чипкин Дмитрий

Игнатович Даниил

контактный телефон:

Руководители:

Бабаева Елена Александровна

Ялышева Анна Владимировна

Новосибирск, 2026

Аннотация проекта

Работа посвящена нейродинамическим процессам регуляции работы ритмов головного мозга , направленного на ежедневную тренировку концентрации внимания. В рамках данного проекта разработано и собрано программируемое биоустройство-тренажер «Сундук сокровищ». Основной идеей устройства является тренинг концентрации внимания за счёт открывания и удерживания расслабленными мышцами лба крышки сундука и нахождении «драгоценных камней» в виде светодиодной ленты при обнаружении датчиком ЭЭГ бета-ритмов.

# Введение

Актуальность

Развитие технологий дает человеку возможности развиваться, решать сложные задачи, но и оказывает негативное влияние на психоэмоциональное состояние людей. Одними из самых распространённых проблем, как среди детей, так и взрослых являются проблемы с концентрацией внимания и рассеянность внимания. Это также связано с различными заболеваниями, например - СДВГ. В наши дни данная проблема является частью науки и активного развития. Столкнувшись с этой проблемой, мы начали искать способы ее решения, что в итоге вылилось в создание нашего устройства, а впоследствии и проекта.

Формирование того или иного психофизиологического состояния связано с активацией/угнетением определённых структур головного мозга. Это сопровождается изменением частотной структуры электроэнцефалограммы – меняется соотношение мощности ритмов ЭЭГ. Так, в состоянии покоя, особенно с закрытыми глазами, наиболее выражен альфа-ритм – активность ЭЭГ в частотном диапазоне 8-12 Гц. При открывании глаз, фокусировке внимания, активном решении каких-либо задач снижается мощность альфа- и повышается мощность бета-ритма – высокочастотной активности в диапазоне 12-20 Гц.

Состояние концентрации также влияет и на лобные мышцы: чем более сосредоточен человек, тем более расслабленные у него мышцы лба и лица в целом.

Созданное устройство будет считывать основные ритмы ЭЭГ и ЭМГ, и помогать тренировать свою внимательность.

Цель: создать устройство, позволяющее тренировать концентрацию внимания.

Задачи:

1. Изучить теоретические основы физиологии человека.

2. Изучить основы работы с Arduino.

3. Разработать схему и собрать устройство.

4. Провести тесты.

Объект исследования: психофизическое состояние человека.

Предмет: Анализ физиологических реакций, регистрируемых в процессе концентрации внимания.

1. ТЕОРИТИЧЕСКАЯ ЧАСТЬ

1.1 МОЗГ

Картинки по запросу "строение мозга"

Головной мозг человека – орган центральной нервной системы, состоящей из множества взаимосвязанных между собой нервных клеток и их отростков. Головной мозг человека занимает почти всю полость мозгового отдела черепа, кости которого защищают головной мозг от внешних механических повреждений. B процессе роста и развития головной мозг принимает форму черепа.

Ритмы головного мозга — диагностируемые электрические колебания головного мозга. В различных состояниях на коре головного мозга человека регистрируются электрические колебания различной амплитуды и частоты. Они были названы ритмами мозга и обозначаются буквами греческого алфавита.

Альфа-волны

Нормальный альфа-ритм на ЭЭГ имеет следующие особенности:

- Частота 8-12 Гц

- Амплитуда: обычно 20-100 мВ;

- Местоположение: затылочные области;

- Морфология: ритмичная и регулярная;

- Реактивность: появляется при закрытии глаз и исчезает при их открытии.

Бета-волны

Нормальный бета-ритм ЭЭГ имеет следующие характеристики:

- Частота (по определению) более 13 Гц;

- Амплитуда: диапазон 5-20 мВ;

- Местоположение: диффузное распространение, более распространен в лобных долях;

- Морфология: обычно ритмичная и симметричная.

- Реактивность: бета-волны в норме связаны с высшими когнитивными процессами и фокусированием внимания, в обычном бодрствующем состоянии, когда мы с открытыми глазами наблюдаем за происходящими событиями, или сосредоточены на решении каких-либо текущих задач.

Тета-волны

Нормальный тета-ритм ЭЭГ имеет следующие характеристики:

- Частота 4-8 Гц;

- Амплитуда: от 20 до 100 мкВ.

- Местоположение: во фронтальных зонах и гиппокампе;

- Реактивность: чаще встречаются во время сонливости и в состояние дрема.

Ритмы ЭЭГ и их характеристика зависят от возраста пациента. В состоянии бодрствования они присутствуют у малышей, однако наличие у взрослых может указывать на дисфункцию или поражение головного мозга.

С использованием этих волн связаны и режимы работы нашего устройства.


1.2 МЫШЦЫ

Лобная мышца (m. frontalis) – поднимает брови и формирует горизонтальные складки лба, когда мы удивляемся.

Фейсбилдинг: упражнения для зоны лба

Основными параметрами поверхностной ЭМГ являются максимальная амплитуда сигнала при измерении ее от пика до пика, средняя амплитуда, средняя частота секундной реализации, средняя амплитуда сигнала. Важным является такой показатель, как амплитудно-частотный коэффициент. До сих пор остается актуальной визуальная оценка рисунка кривых. Ниже на рисунках (Рис. 1.6 — 1.8) представлены типы поверхностной ЭМГ, выделенные Ю.С. Юсевич (1958).

I ТИП ЭМГ характерен для нормальной мышцы и отражает суммарную активность большого числа ДЕ при максимальном сокращении (Рис. 1.6). Частота интерференционной кривой в норме около 50 Гц, амплитуда 1-2 мВ. Выраженное их снижение свидетельствует о выпадении части мышечных волокон из ДЕ и наблюдается при первичных мышечных или аксональных процессах. С дифференциально-диагностическими целями в первом случае целесообразно исследование ПДЕ с помощью игольчатых электродов, во втором - оценка СРВ (скорость распространения возбуждения) и параметров вызванного ответа мышцы и нерва путем стимуляционной ЭМГ.


II ТИП ЭМГ характеризуется относительно редкой ритмической активностью, возникающей в покое. IIа тип имеет частоту 6-200 Гц, амплитуду 50-150 мкВ, IIб тип - 21-50 Гц, 300-500 мкВ (Рис. 1.7). Подтипы IIа и IIб характеризуют степень выраженности патологического процесса, причем IIб свидетельствует о менее грубом поражении мотонейронов и в начальных стадиях заболевания лучше выявляется при тонических пробах.


III ТИП ЭМГ отмечается при супрасегментарных процессах и включает в себя два подтипа: частые ритмические разряды при треморе (Рис. 1.8) и усиление активности покоя при экстрапирамидной ригидности. Гиперкинезы сопровождаются нерегулярными артефактными разрядами, соответствующими насильственным движениям. Параметры СРВ и ПДЕ в этих случаях практически не изменяются, поэтому применение стимуляционной и игольчатой ЭМГ не обязательно.


IV ТИП ЭМГ характеризуется биоэлектрическим молчанием мышцы при попытке произвольного сокращения. Полный паралич может быть связан с острой невропатией, вялой стадией пирамидного паралича, атрофией мышечной ткани различного генеза. Для дифференциальной диагностики уровня поражения показано исследование СРВ по периферическим нервам и анализ параметров ПДЕ с применением игольчатых электродов.

1.3 ОТСЛЕЖИВАНИЕ ФИЗИОЛОГИЧЕСКИХ ПАРАМЕТРОВ ЧЕЛОВЕКА

Электроэнцефалограмма (ЭЭГ) — графическое изображение сложного колебательного электрического процесса, который регистрируется при помощи электроэнцефалографа при размещении его электродов на мозге или поверхности скальпа, результат электрической суммации и фильтрации элементарных процессов в нейронах.

# Принцип работы:

Регистрация ЭЭГ производится при помощи электроэнцефалографа через специальные электроды (наиболее распространенные — мостиковые, чашечковые и игольчатые). В настоящее время чаще всего используется расположение электродов по международным системам «10—20 %» или «10—10 %». Каждый электрод подключен к усилителю. Для записи ЭЭГ может использоваться бумажная лента (это устаревший вариант, широко применяемый во времена СССР и РФ вплоть до конца 2000-х годов) или сигнал может преобразовываться с помощью АЦП и записываться в файл на компьютере (современный вариант). Наиболее распространена запись с частотой дискретизации 250 Гц. Запись потенциалов с каждого электрода осуществляется относительно нулевого потенциала референта, за который, как правило, принимается мочка уха или сосцевидный отросток височной кости (processusmastoideus), расположенный позади уха и содержащий заполненные воздухом костные полости.

Система «10—20%» — стандартная система размещения электродов на поверхности головы, которая рекомендована Международной федерацией электроэнцефалографии и клинической нейрофизиологии. Была создана в 1950-х годах канадским нейрофизиологом Гербертом Генри Джаспером.

21 electrodes of International 10-20 system for EEG.svg

Аналого-цифровой преобразователь — устройство, преобразующее входной аналоговый сигнал в дискретный код (цифровой сигнал).

Биологическая обратная связь - технология, включающая в себя комплекс исследовательских, немедицинских, физиологических, профилактических и лечебных процедур, в ходе которых человеку посредством внешней цепи обратной связи, организованной преимущественно с помощью микропроцессорной или компьютерной техники, предъявляется информация о состоянии и изменении тех или иных собственных физиологических процессов.

БОС-процедура заключается в непрерывном мониторинге в режиме реального времени определённых физиологических показателей и сознательном управлении ими с помощью мультимедийных, игровых и других приемов в заданной области значений.

Быстрое преобразование Фурье (англ. Fast Fourier Transform, FFT) — метод, позволяющий вычислять дискретное преобразование Фурье за время O(N²)

Преобразование Фурье (https://ru.wikipedia.org/wiki/%D0%A4%D1%83%D1%80%D1%8C%D0%B5,_%D0%96%D0%B0%D0%BD_%D0%91%D0%B0%D1%82%D0%B8%D1%81%D1%82_%D0%96%D0%BE%D0%B7%D0%B5%D1%84) — операция, сопоставляющая одной функции вещественной переменной другую функцию вещественной переменной.

Электромиография (ЭМГ, ЭНМГ, миография, электронейромиография) — (мио - мышцы и …графо - пишу), метод исследования биоэлектрических (см. Электрофизиология) потенциалов, возникающих в скелетных мышцах человека и животных при возбуждении мышечных волокон; регистрация электрической активности мышц.

# Принцип работы:

После прихода нервного импульса к концевой пластинке (место контакта веточки двигательного нерва и мышцы, рисунок 1 А) происходит деполяризация (в течение 0,5 мс) постсинаптической мембраны мышечного волокна. Деполяризация мембраны мышечных клеток обусловлена движением внутрь ионов Na+ (рисунке 1 Б). Процесс деполяризации распространяется в обе стороны от концевой пластинки со скоростью 2-6 м/c (рисунок 1В). Расположенные в этом поле электроды регистрируют напряжение (электрический потенциал) мышечных волокон. Если электроды расположить вдоль мышечных волокон, то электрический сигнал волокон по форме будет биполярным и знак первой волны будет зависеть от расположения электрода по отношению к волокнам. ЭС волокон с моторными пластинками, расположенными справа от электродов, имеют отрицательный знак, слева – положительный (рисунок 1 Б).
Схематическое представление электромиограммы отдельных двигательных единиц и суммарная миограмма мышцы представлены на рисунке 2.
Амплитуда ЭС зависит от диаметра волокон, расстояния от активированного мышечного волокна, размеров регистрируемой области и фильтрующих свойств электродов. Для тканей человека амплитуда ЭС возрастает пропорционально V=ka1,7, где а радиус мышечного волокна и k — константа. Снижение амплитуды сигнала обратно пропорционально расстоянию до активного волокна и регистрируемой площади. Фильтрующие свойства биполярных электродов зависят от размеров, расстояния между электродами и материала изготовления.

А


Б. В.

# 1.4 Arduino

  Arduino — это электронный конструктор и удобная платформа быстрой разработки электронных устройств для новичков и профессионалов. Платформа пользуется огромной популярностью во всем мире благодаря удобству и простоте языка программирования, а также открытой архитектуре и программному коду. Устройство программируется через USB без использования программаторов.

Arduino позволяет компьютеру выйти за рамки виртуального мира в физический и взаимодействовать с ним. Устройства на базеArduino могут получать информацию об окружающей среде посредством различных датчиков, а также могут управлять различными исполнительными устройствами.

Микроконтроллер на плате программируется при помощиC++ и среды разработки Arduino (основана на среде Wiring). Проекты устройств, основанные на Arduino, могут работать самостоятельно, либо же взаимодействовать с программным обеспечением на компьютере. Платы могут быть собраны пользователем самостоятельно или куплены в сборе. Программное обеспечение доступно для бесплатного скачивания (http://arduino.cc/en/Main/Software). Исходные чертежи схем (файлы CAD) являются общедоступными, пользователи могут применять их по своему усмотрению.

# 2. Практическая часть

# 2.1. Оборудование

Arduino Mega — это расширенная версия популярной платформы быстрой разработки электронных устройств, предназначенная для более сложных проектов, требующих большого количества выводов и памяти. Платформа пользуется огромной популярностью во всем мире благодаря удобству и простоте языка программирования, а также открытой архитектуре и программному коду. Устройство программируется через USB без использования программаторов.

Arduino Mega позволяет компьютеру выйти за рамки виртуального мира в физический и взаимодействовать с ним. Устройства на базе Arduino могут получать информацию об окружающей среде и состоянии человека посредством различных датчиков, а также могут управлять различными исполнительными устройствами.

Микроконтроллер на плате программируется при помощи языка Arduino (основан на языке Wiring) и среды разработки Arduino (основана на среде Processing). Проекты устройств, основанные на Arduino, могут работать самостоятельно, либо же взаимодействовать с программным обеспечением на компьютере. Платы могут быть собраны пользователем самостоятельно или куплены в сборе. Программное обеспечение доступно для бесплатного скачивания. Исходные чертежи схем являются общедоступными, пользователи могут применять их по своему усмотрению.

Компоненты проекта:

- Провода штекер-штекер – соединяют макетную плату, датчики и Arduino Mega.
- Датчики ЭЭГ и ЭКГ от Bitronicks – анализируют информацию, полученную от электродов (биопотенциалы мозга и сердца).
- Кабель ПК-ARDUINO – подключает Arduino к компьютеру для программирования и передачи данных.

BB-801, Плата макетная беспаечная 55х82х8.5 мм – купить оптом и в розницу

- Макетная беспаечная плата – соединяет датчики, светодиодную панель и Arduino без пайки.

Bi-Color (Red/Green) 12-LED Bargraph - Pack of 2 : Adafruit Industries, Unique & fun DIY electronics and kits

- LED панель с 10 светодиодами – визуализирует состояние системы.

Сервопривод Feetech FS5106B / 180° / Купить с доставкой по России / Амперка

- Сервопривод – “умный” электродвигатель, который умеет поворачиваться на точно заданный угол или двигаться с определенной скоростью, а затем удерживать это положение.


Датчики регистрации физиологических сигналов (Bitronicks)

- Модуль ЭЭГ: Одноканальный или многоканальный модуль передачи данных с датчика ЭЭГ. Осуществляет регистрацию электрических потенциалов головного мозга.
- Модуль ЭКГ: Датчик регистрации электрокардиограммы, использует поверхностные электроды для снятия сигнала с тела.

Внутренняя структура модулей передачи данных:

Внутри модули Bitronicks представлены несколькими блоками:

- Усилитель физиологического сигнала.
- АЦП (аналогово-цифровой преобразователь).
- Порт передачи данных
- Источник питания.

Подключение к ПК:

Arduino Mega, как и ПК, имеет встроенный интерфейс USB. Соединение осуществляется напрямую через кабель USB Type-B. Работа с устройством организована через порт последовательной передачи данных (Serial). Данные передаются на компьютер для отображения в мониторинге или управления внешним ПО.

Программное обеспечение комплекса включает в себя:

- Микропрограммы (скетчи) для Arduino Mega, обрабатывающие сигналы с датчиков Bitronicks.
- Библиотеки для работы с датчиками ЭЭГ и ЭКГ.
- Программное обеспечение для ПК (мониторинг, визуализация).

# 2.2. Биологическая часть

Для всех сигналов используются алгоритмы базовой программной обработки и расширенные алгоритмы обработки, позволяющие получать производные физиологические сигналы и(или) их характеристики. Базовые алгоритмы обработки включают в себя фильтры для очистки от помех.

Расширенные алгоритмы обработки зависят от характера физиологического сигнала:


##### Визуализация мышечных сокращений (рисунок 1.1):

##### Рисунок 1.1

Электроэнцефалограмма (ЭЭГ) Вычисляются: альфа-бета-тета-ритмы


# 2.3 Схема устройства


2.4 3D-модель сундука

# 2.4 Программная часть

#include <arduinoFFT.h>

arduinoFFT FFT = arduinoFFT();

#define size 64

#include <SoftwareSerial.h>

#include <Servo.h>

Servo mas;

unsigned long last_time;

SoftwareSerial piSerial(10, 11);

void uniorBegin(/*const int channel, int number_of_channels*/)

{

piSerial.begin(57600);

piSerial.write(0xff);

while (true)

{

String s = piSerial.readString();

Serial.print(s);

if (s == "OK\n")

{

Serial.println("Get OK! GO!");

String s;

s += 0;

s += ";";

s += 3;

piSerial.println(s);

Serial.println(s);

break;

}

}

}

bool uniorRead(uint8_t channel_no, float& value)

{

while (piSerial.available()) piSerial.read();

piSerial.write(channel_no);

int readCnt = piSerial.readBytes((byte*)&value, sizeof(float));

// Serial.println(value);

return (readCnt == sizeof(float)) && (value == value);

}

const int cEEG1 = 0;

const int cEMG1 = 3;

//const int ch = {cEMG1};

double M[64];

double O[64];

void setup() {

// put your setup code here, to run once:

last_time = millis();

mas.attach(9);

mas.write(0);

Serial.begin(115200);

Serial.println("Serial port started with 115200");

uniorBegin();

pinMode(7, OUTPUT);

for ( int i = 0; i < 64; i++) {

O[i] = 0;

}

}

int i = 0;

double mx = M[0];

int u = 0;

void loop() {

// put your main code here, to run repeatedly:

float v;

float w;

if (uniorRead(cEEG1, v) && uniorRead(cEMG1,w)) //(uniorRead(cEMG1,w))

{

// Serial.println(w);

M[i] = v;

i++;

Serial.println(w);

if(w<20 and u==0){

for(int a=0; a<70; ){

if(millis()-last_time>150){

mas.write(a);

a+=1;

last_time=millis();

}

}

u=90;

}

else{

if(w>20 and u==90){

for( int g=70; g!=0; ){

if(millis()-last_time>150){

mas.write(g);

g-=1;

last_time=millis();

}

}

u=0;

}

}

if(i==64){

FFT.Compute(M, O, 64, FFT_FORWARD);

FFT.ComplexToMagnitude(M, O, 64);

for(int p = 0; p<64; p++){

if (M[i] > mx){

mx = M[i];

}

}

for(int e = 16; e<32; e++){

if(M[e]>= 0.6 * mx){

Serial.println("beta ritm");

digitalWrite(7, HIGH);

break;

}

}

for (int x = 0; x < 64; x++){

O[x] = 0;

}

}

}

}

# 2.5 Принцип работы устройства

Приём данных:

Модуль сопряжения принимает данные, пришедшие от беспроводных модулей, и передаёт их на Ардуино, программа на Ардуино фильтрует сигнал и для датчика ЭЭГ сравнивает максимальные значения в поисках бета-ритма, а для ЭМГ значения не выше определённого порога напряжения.

Алгоритм работы:

Код постоянно обрабатывает данные с ЭМГ датчика и при определённом значении (когда мышцы расслаблены) открывает крышку сундука. Параллельно с этим код обрабатывает данные с датчика ЭЭГ и при нахождении значений бета-ритма, зажигает светодиод внутри сундука.

# 2.6 Стоимость проекта

Для реализации нам потребовались: датчики юниор ЭЭГ и ЭМГ, резистор, светодиод, макетная плата, Arduino Uno, ноутбук с программным обеспечением Arduino, шаговый двигатель и драйвер к нему, соединительные провода, материалы для сундука(дерево).

# Вывод:

Мною были изучены теоретические аспекты по теме «ритмы encephalon», разработано устройство, написана программная часть в среде разработки «Arduino IDE» на языке программирования C++. Проблемы, которые могут быть решены с помощью нашего устройства:

- Развитие внимательности у детей;
- Помощь людям с проблемами в концентрации;
- Улучшение работоспособности у учащихся.

Перспективы: улучшение конструкции сундука, возможно добавление новых функций.

Более обширное использование программно-аппаратного комплекса “Юный нейроисследователь” (ПАК ЮНИор), разработанного ООО «КОМСИБ» и НГУ (г. Новосибирск). Проведение исследования на конкретных людях.

# Литература

1. Блум Ф., Лейзерсон А., Хофстедтер Л. Мозг, разум и поведение. — М., 1988.
2. Быков М. П. Анатомия головного мозга. Фотографический атлас, Практическая медицина, 2009 г
3. Кирой В. Н., Ермаков П. Н. Общая характеристика ритмов ЭЭГ человека // Электроэнцефалограмма и функциональные состояния человека. — Ростов-на-Дону: Изд-во Рост. ун-та, 1998.
4. www.bitronicslab.com
5. https://роботехника18.рф
6. Гусельников В. И. Электрофизиология головного мозга. — М.: Высшая школа, 1976.
7. Иванов Л. Б. Прикладная компьютерная электроэнцефалография. — М.: Антидор, 2000.
8. Штарк М. Б., Шварц М. Биоуправление-4. Теория и практика. — Новосибирск: ЦЭРИС, 2002.
9. Lubar J. F., Lubar J. O. Neurofeedback assessment and treatment for attention deficit/hyperactivity disorders.//In: Introduction to quantitative EEG and Neurofeedback. Eds.: Evans J.R. &Abarbanel A., 1999
10. Нуссбаумер Г. Быстрое преобразование Фурье и алгоритмы вычисления сверток. — М.: Радио и связь, 1985.
11. http://www.physexperiment.narod.ru/methodics/fmb10.pdf

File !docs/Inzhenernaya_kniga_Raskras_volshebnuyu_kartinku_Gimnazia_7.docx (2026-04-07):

муниципальное автономное общеобразовательное учреждение

города Новосибирска

«Гимназия №7 «Сибирская»

Инженерная книга

«Раскрась волшебную картинку»

Авторы работы:

Ученики 10 «Б» класса Ковалева Дарья

и Рендин Владислав 8 «А»

Руководители: Бабаева Елена Александровна

Ялышева Анна Владимировна

Гурских Владислав Романович

Новосибирск 2025

Введение

Мышцы — органы, состоящие из мышечной ткани; способны сокращаться под влиянием нервных импульсов. Часть опорно-двигательного аппарата. Выполняют различные движения, обеспечивая перемещение тела, поддержание позы, сокращение голосовых связок, дыхание и прочее. Мышечная ткань упруга и эластична; состоит из миоцитов (мышечных клеток). Для мышц характерно утомление, которое проявляется при интенсивной работе или нагрузке.

Релакса́ция (от лат. relaxatio — ослабление, расслабление) — процесс расслабления, сопровождающегося снятием психического напряжения. Релаксация может быть, как непроизвольной, так и произвольной, достигнутой в результате применения специальных психофизиологических техник.

В основе теории релаксации лежит утверждение, что разум и тело человека тесно взаимосвязаны. Предполагается, что человек в состоянии психического (эмоционального) напряжения испытывает и физическое (телесное) напряжение. И наоборот: человек в состоянии физического напряжения начинает испытывать и напряжение психическое. Следовательно, для того, чтобы расслабить тело, нужно расслабить разум (и наоборот); а психическое расслабление ведёт к расслаблению физическому, телесному. Воплощением этого вывода и занимается осознанная релаксация.

Актуальность. Биология и биотехнологии сегодня способны отвечать на глобальные вызовы человечеству и сделать нашу жизнь комфортнее и безопаснее. Медицинская реабилитация — непростое испытание. Восстановление занимает месяцы и годы. Большинство пациентов не в состоянии оправиться от болезни и продолжают жить с не долеченными симптомами, что приводит к очередным ударам, физическим и психологическим. Ранняя интенсивная реабилитация дает неплохие результаты, но только треть пациентов продолжает рекомендуемую терапию дома. Наше устройство будет представлять из себя игру-тренажер, которая будет способствовать улучшению мышечной активности. Также нужно отметить то, что детям сложнее найти мотивацию делать монотонные длительные упражнения, поэтому игровая форма будет как нельзя кстати. Поэтому такой тренажер будет интересен и полезен не только детям, но и взрослым. Помимо этого, благодаря данному проекту может быть проведена диагностика мышечных показателей с целью их улучшения.

Цель: Превратить черно-белую или в оттенках серого картинку на мониторе в полноцветную, управляя физиологическими параметрами.

Задачи:

1. Изучить теоретические аспекты по теме «биоэлектрическая активность мышц».
2. Разработать схему устройства, собрать его.
3. Разработать интерфейс игры.
4. Запрограммировать игру и её интерфейс с использованием языка программирования C#.
5. Протестировать игру.
6. Проанализировать результаты

# 1. Теоретическая часть

1.1. Работа мышц

Работа бывает динамическая и статической. Если при работе мышц происходят движения в суставах, то ее называют динамической. Если суставы неподвижны, то работа мышц заключается в поддержании тела в определенном положении. В таком случае мышечную работу называют статической. Легко понять, чем отличается динамическая и статическая работа мышц: в первом случае суставы совершают движение, во втором случае – остаются неподвижно. Ключевой характеристикой динамичной работы мышц является энергозатратность. Несмотря на то, что мышцы тратят энергию в статике, во время активного движения ее затрачивается в разы больше.

Под динамической работой мышц подразумевается двигательная активность, при которой происходит попеременное расслабление и сокращение мышц для перемещения тела в пространстве или выполнения определенного движения. При выполнении динамической работы происходят физиологические реакции организма, которых не возникает во время статической мышечной работы. Примером таких реакций служит увеличение пульса и артериального давления во время активности. Интенсивность проявления реакций зависит от разных факторов: тренированности человека, силы и частоты мышечного сокращения, и даже от того, в каком положении находилось тело до начала активности.

Динамическая работа мышц может быть преодолевающей и уступающей, что значит преодоление сопротивления и непротиводействие. Рассмотрим на примере мышц рук: при отведении выполняется преодолевающая динамическая работа, при приведении – уступающая. А при удержании руки в определенном положении выполняется статическая или удерживающая работа мышц.

Даже если человек находится в неподвижном положении, его мышцы все равно производят работу, поддерживая корпус и координируя тело в пространстве. В теле человека огромное количество мышц, объединенных в группы, которые работают слаженно, обеспечивая нормальную двигательную активность. Существуют статические и динамические мышцы.

# 1.2. Миография

И. Кант писал: «Рука это – вышедший наружу головной мозг». Своеобразным «питанием» для головного мозга являются импульсы (афферентные) от рецепторов двигательной сферы. Для гармоничного развития необходимо регулярное снабжение мозга такими импульсами. В свою очередь, руки должны регулярно и много двигаться. Согласно основным положениям теории функциональных систем (П.К. Анохин, 1975г., К.С. Судаков, 1983г.), для генерации «полезного результата», необходимо психофизиологическое, адресованное воздействие на высшие регуляторные центры кинестетического анализатора, с целью кинестетической и когнитивной коррекции функциональной активности тоногенных и координаторных нейроструктур, формирующих сложнорефлекторные двигательные реакции.

Механизм мышечного сокращения.

Picture background

Рис.1

Мышцы лба (или лобная мышца) являются частью мимической мускулатуры лица и отвечают за движения кожи лба. Основные функции этой мышцы включают подъем бровей и образование поперечных складок на лбу при выражении удивления или волнения.

Структура и анатомия: Лобная мышца берет свое начало от сухожильного шлема (апоневроза), который покрывает череп.

Прикрепление: Мышечные волокна переходят в кожу бровей.

Иннервация: Лицевой нерв (VII пара черепно-мозговых нервов).

Кровоснабжение: Надблоковая артерия и поверхностная височная артерия.

Функции

1. Подъем бровей: Когда лобная мышца сокращается, она тянет кожу вверх, поднимая брови. Это движение часто ассоциируется с выражением удивления или внимания.
2. Образование морщин: При сильном сокращении мышцы образуются горизонтальные морщины на лбу, что также является характерной чертой мимики.

Структурная организация мышечного волокна. Структура мышечного волокна мышц лба, как и всех скелетных мышц, включает несколько ключевых компонентов, обеспечивающих способность к сокращению и расслаблению.

Сокращение мышц лба вызывается нервными импульсами, исходящими из головного мозга через лицевые нервы (VII пара черепно-мозговых нервов). Этот процесс состоит из нескольких этапов:

1. Нервный сигнал: Мозг посылает электрический сигнал по лицевым нервам к моторным нейронам, иннервирующим лобную мышцу.
2. Передача сигнала: Сигнал передается от моторного нейрона к мышечному волокну через синапс — место контакта между нервной и мышечной клеткой. Здесь выделяется нейромедиатор ацетилхолин, который связывается с рецепторами на поверхности мышечного волокна.
3. Возбуждение мышечного волокна: Связывание ацетилхолина вызывает деполяризацию мембраны мышечного волокна, что запускает каскад событий, приводящих к сокращению.
4. Выход кальция: Деполяризация мембраны открывает кальциевые каналы в саркоплазматическом ретикулуме, что приводит к высвобождению ионов кальция в цитоплазму мышечного волокна.
5. Активация тропонина и тропомиозина: Кальций связывается с белком тропонином, вызывая изменение конформации тропонин-тропомиозинового комплекса, что позволяет головкам миозина взаимодействовать с актином.
6. Скользящее взаимодействие актин-миозин: Головки миозина присоединяются к актину и перемещаются вдоль него, что приводит к укорочению саркомеров и общему сокращению мышечного волокна.
7. Расслабление: После прекращения стимуляции уровень кальция в саркоплазме снижается благодаря активности кальциевого насоса, возвращающего кальций обратно в саркоплазматический ретикулум. Это приводит к разъединению актин-миозиновых мостиков и расслаблению мышцы.

Методы:

Миография, или электронейромиография (ЭНМГ) — это метод диагностики, при котором регистрируют электрическую активность мышц в покое и во время сокращений.

  Всякое мышечное волокно сокращается за счет происходящих в нем электрохимических реакций. Возникает электрический потенциал. При поверхностной миографии на кожу накладывают два металлических электрода. Они регистрируют суммарные электрические импульсы от многих мышечных волокон, находящихся рядом.


  Рис 2

Электромиография (ЭМГ) представляет собой запись электрической активности мышц. Электрическая активность — это мышечные потенциалы действия от мышечных волокон. Мышечные волокна одного мотонейрона распределены в мышце так, что они редко располагается рядом. При активации моторной клетки почти синхронно деполяризуются все относящиеся к ней мышечные волокна, и эти потенциалы действия мышечных волокон суммируются в потенциал действия моторной единицы (ПДМЕ). Считается по разности потенциалов «точки покоя» (L1) и полученного сигнала с мышцы (L2).


Рис.3


Рис.4

Активность регистрируется с помощью записи от электрода, который вводится в мышцу. Более удаленные мышечные волокна вносят вклад только в начале и в конце потенциала действия и тем самым определяют продолжительность ПДМЕ.

Число активных двигательных единиц зависит от силы сокращения мышцы. Во время расслабления только одна или несколько моторных единиц имеют активные волокна у электрода. Поэтому именно во время расслабления мышц можно записать ПДМЕ.

При увеличении силы сокращения два явления происходят одновременно: частота сокращения уже активированных моторных единиц увеличивается, и к ним присоединяются новые двигательные единицы. Во время максимального сокращения ПДМЕ будут суммироваться.

Во время проведения электромиографии (ЭМГ) активность записывается с нескольких точек подряд внутри мышцы, для того чтобы измерить активность двигательных единиц исследуемой зоны. Активность оценивается в покое, а также при слабом и максимальном произвольном сокращении мышц.

Свойства ПДМЕ (длительность, амплитуда, количество фаз), а также частота генерации импульсов, конфигурация интерференционной картины и спонтанная электрическая активность мышц в покое являются параметрами, которые получают при ЭМГ. Структура моторных единиц изменяется по-разному при первичных мышечных заболеваниях (миопатии) и после повреждения двигательных нервов.

Снижение количества мышечных волокон на двигательную единицу также приводит к уменьшению амплитуды потенциалов. Увеличение числа мышечных волокон в моторной единице, вызванное периферическим прорастанием с реиннервацией мышечных волокон, увеличивает количество мышечных волокон на каждую моторную единицу и тем самым увеличивает длительность и амплитуду потенциала действия мышцы.

Амплитуда ПДЕ 350-700 мкВ у здорового человека.

  Кинезиотерапия - лечение движением предполагает адаптированные, постепенно возрастающие силовые воздействия, определённые строго индивидуально для каждого пациента, с учётом его анамнеза, возрастных, физиологических и других особенностей и других заболеваний, сопутствующих основному. Постепенное обучение правильным (простым и сложным) движениям приводит к их нейрорефлекторному закреплению и восстановлению трофики (питания) и обмена веществ в костно-мышечной системе человека. В нашем случае известную формулу «движение лечится движением» можно перефразировать как «движение лечится скорригированным движением». Двигательные задачи, которые могут быть решены с помощью нашего тренажера - развитие мышечного чувства и нахождение правильного движения; - улучшение сократительной способности определенной мышцы или группы мышц; - улучшение отношений при произвольном движении; - устранение непроизвольных движений; - тренировка опороспособности.

# 1.3. C#

C# («си шарп»)— объектно-ориентированный язык программирования. Разработан в 1998—2001 годах группой инженеров компании Microsoft под руководством Андерса Хейлсберга и Скотта Вильтаумота как язык разработки приложений для платформы Microsoft .NET Framework, впоследствии был стандартизирован. C# относится к семье языков с C-подобным синтаксисом, из них его синтаксис наиболее близок к C++ и Java. Язык имеет статическую типизацию, поддерживает полиморфизм, перегрузку операторов, атрибуты, события, свойства, обобщённые типы и методы, итераторы, анонимные функции, LINQ, исключения, комментарии.С помощью C# можно разрабатывать сайты (ASP.NET), клиентские и web-приложения, кроссплатформенные мобильные приложения и игры в Unity 3D и CryEngine.

# 2. Практическая часть

# 2.1. Биологическая часть

##### Визуализация мышечных сокращений (рисунок 1.1):

Распространение сигнала вдоль мышцы и суммирование активности нескольких мышечных волокон (рисунок 1.2).

##### Рисунок 1.2

Аппаратная часть

Наш проект создан с использованием оборудования, входящего в программно-аппаратный комплекс «Юный нейроисследователь» (ПАК ЮНИор), который разработан российским производителем ООО «Комсиб» (г. Новосибирск). ПАК ЮНИор предназначен для обучения принципам и методам регистрации и обработки электрофизиологических и психофизиологических сигналов человека. Это инструментальная среда изучения нейротехнологий (как по инженерному направлению биоинжениринга, так и научно-исследовательской деятельности в области нейрокогнитивных наук), включающей аппаратную, программную и учебно-методическую компоненты, позволяющую организовать обучение школьников и их наставников в форме проектной деятельности с элементами соревнования.

Он позволяет визуализировать сигналы на персональном компьютере, создавать элементы управления внешними устройствами, а также системы биоуправления для исследований, коррекции и реабилитации различных патологических состояний, оценки показателей стрессоустойчивости, внимания и других когнитивных процессов.

Программно-аппаратный комплекс БОСЛАБ состоит из:

- двух беспроводных одноканальных модулей ЭЭГ и ЭМГ, которые соединяются с компьютером через USB-адаптер (Bluetooth-адаптер);
- комплекта соответствующих датчиков и электродов;
- программной системы «БОСЛАБ».

В проекте использовалось следующее оборудование:

1. Датчик регистрации ЭЭГ

Датчик включает в себя два активных электрода для регистрации электрических потенциалов головного мозга, которые фиксируются на коже головы с помощью специальной электропроводной пасты, и

заземляющего электрода (накладывается на мочку уха). Активные электроды накладываются биполярно. Для получения более мощного сигнала ЭЭГ и упрощения регистрации рекомендуем использовать лобно-затылочные отведения, например, точки F4-O2. Точка F4 находится по линии правого глаза на уровне пересечения с границей роста волос. Точка О2 - в районе правого затылочного бугра.

Подключение к беспроводному модулю передачи данных осуществляется через разъём microUSB.

2. Одноканальный беспроводной модуль передачи данных.

Внутри модуль представлен несколькими блоками:

- Усилитель физиологического сигнала
- 24 разрядный АЦП (аналогово-цифровой преобразователь)
- Блок беспроводной передачи данных Bluetooth4 /BLE (Bluetoothlowenergy)
- Источник питания и заряда литиевого аккумулятора
- Синхронизация данных по времени

Для заряда аккумулятора используется отдельная схема от внешнего источника питания напряжением 5 вольт.

Беспроводной модуль регистрации ЭМГ фиксируется на голове с помощью резинового ободка.


Рис.2.1 Беспроводной модуль регистрации ЭМГ

Рис.2.2 Датчик регистрации ЭМГ

Датчик представлен тремя кнопочными разъёмами для крепления одноразовых поверхностных электродов, которые обеспечивают контакт с поверхностью кожи и регистрацию электрических потенциалов мышц. Два «хвоста» (одного цвета) – это активные электроды, третий (отличающийся по цвету) – заземляющий электрод. Заземляющий электрод накладывается по центру лобной мышцы, активные – по бокам от него

Рис.2.3 Электроды

Одноразовые электроды обеспечивают высококачественную регистрацию сигнала при долговременном и краткосрочном мониторинге ЭМГ. Электроды комфортны, не аллергенны, при обследовании не вызывают раздражений. Материал носителя – высококачественный водонепроницаемый вспененный полиэтилен с двухкомпонентной гелевой пропиткой на подложке из пенополиуретана. Крепление к держателю электрода кнопочное. В адгезивных электродах подложка из нетканого материала высокого качества, покрыта прочным электропроводящим клеем, обеспечивающим надежное прилипание.

3. USB-адаптер (Bluetooth-адаптер) - служит для передачи данных в компьютер через USB порт.


Рис. 2.4. USB-адаптер (Bluetooth-адаптер)


  3.1 Прототип устройства
  2.3 Эксперимент

Для проведения сеансов релаксационного ЭМГ тренинга была использована закладка «ЭМГ тренинг» из раздела РЕЛАКС библиотеки сессий.


Испытуемый 1:

Тест 1:

Вычисление порога:


ЭМГ- тренинг:


Тест 2:

Вычисление порога:


ЭМГ- тренинг:


Испытуемый 2:

Тест 1:

Вычисление порога:


ЭМГ- тренинг:


4. Программная часть

4.1 Интерфейс:


Рис.4.1 Начальная картинка


Рис.4.2 Конечная картинка

4.2 Код:

using System.Text;

using System.Collections.Generic;

using UnityEngine;

using System.Net;

using System.Net.Sockets;

using System;

public class NewBehaviourScript : MonoBehaviour

{

Socket socket = new Socket(AddressFamily.InterNetwork, SocketType.Stream, ProtocolType.Tcp);

int port = 9090;

string url = "127.0.0.1";

// Start is called before the first frame update

void Start()

{

try

{

// пытаемся подключиться используя URL-адрес и порт

socket.Connect(url, port);

Debug.Log("Подключение установлено");

}

catch (SocketException)

{

Debug.Log("Не удалось установить подключение");

}

}

// Update is called once per frame

void Update()

{

while (socket.Available > 0)

{

byte[] dat = new byte[socket.Available];

int tem = socket.Receive(dat);

double[] dat2 = new double[tem/8];

for(int i=0; i<tem; i+=8)

{

dat2[i / 8] = BitConverter.ToDouble(dat, i);

Debug.Log(dat2[i/8]);

}

}

}

}

}

if (DATA.canStartOver == false)

{

DATA.canStartOver = true;

}

this.Close();

}

else TimeToExit++;

}

}

}

}

}

Выводы

Было создано биоуправляемое устройство-тренажер, позволяющее исследовать и контролировать биоэлектрическую активность мышц, с визуальной составляющей – игрой на основе ЭМГ.

В нашей работе мы использовали данные получаемые с мышц лба.

Результаты

- Мы изучили теоретические аспекты по теме «биоэлектрическая активность мышц» и выявили погрешность для каждого человека, так, разделили
- Разработали интерфейс игры.
- Запрограммировали игру с использованием языка программирования C# в среде VisualStudio и .NetFramework на C#.
- Протестировали игру.

Литература

- Приложение к руководству пользователя «БОСЛАБ ЮНИор» для беспроводных модулей ЭЭГ и ЭМГ.
- Петин В.А. Проекты с использованием контроллера Arduino. — БХВ-Петербург, 2014. — 400 с. Учебно-методическое пособие к набору конструктору «Юный нейромоделист» BiTronics Lab
- BiTronics Lab Studio Руководство пользователя

Интернет-источники:

- Видеоуроки BiTronics Lab hlips://www.youtube.eom/channel/lJC-GF1СvXMN8c- (http://www.youtube.eom/channel/lJC-GF1%d0%a1vXMN8c-) 9aNx3c-8tzng
- Курс по биосенсорам hitps://ru.coursera,o.rg/leai-n/biosen$oiT
- Курс по биомеханике https://openedii.ru/course/spbstu/BIOMECH/
- https://bodybuilding-and-fitness.ru/myshcy/ruki/biceps
- www.bitronicslab.com/
- https://ru.wikipedia.org/wiki/C_Sharp
- https://www.arduino.cc/reference/en/
- https://meduniver.com/Medical/Anatom/108.html

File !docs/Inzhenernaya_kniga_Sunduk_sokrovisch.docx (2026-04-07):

Муниципальное автономное общеобразовательное учреждение

города Новосибирска

«Гимназия №7 «Сибирская »

Инженерная книга

«Сундук сокровищ»

Авторы работы:

Бамбурова Дарья Николаевна 9Г

Куравкин Степан, 7А

Киселева Лелия 10Б

контактный телефон: +79833186573

Руководители:

Бабаева Елена Александровна

Ялышева Анна Владимировна

Новосибирск, 2022

Аннотация проекта

Работа посвящена нейродинамическим процессам регуляции работы ритмов головного мозга , направленного наежедневную тренировку концентрации внимания. В рамках данного проекта разработано и собрано программируемое биоустройство-тренажер «Сундук сокровищ». Основной идеей устройства является тренинг концентрации внимания за счёт открывания и удерживания расслабленными мышцами лба крышки сундука и нахождении «драгоценных камней» в виде светодиодной ленты при обнаружении датчиком ЭЭГ бета-ритмов.

# Введение

Актуальность

Развитие технологий дает человеку возможности развиваться, решать сложные задачи, но и оказывает негативное влияние на психоэмоциональное состояние людей. Одними из самых распространённых проблем, как среди детей, так и взрослых являются проблемы с концентрацией внимания и рассеянность внимания. Это также связано с различными заболеваниями, например - СДВГ. В наши дни данная проблема является частью науки и активного развития. Столкнувшись с этой проблемой, мы начали искать способы ее решения, что в итоге вылилось в создание нашего устройства, а впоследствии и проекта.

Формирование того или иного психофизиологического состояния связано с активацией/угнетением определённых структур головного мозга. Это сопровождается изменением частотной структуры электроэнцефалограммы – меняется соотношение мощности ритмов ЭЭГ. Так, в состоянии покоя, особенно с закрытыми глазами, наиболее выражен альфа-ритм – активность ЭЭГ в частотном диапазоне 8-12 Гц. При открывании глаз, фокусировке внимания, активном решении каких-либо задач снижается мощность альфа- и повышается мощность бета-ритма – высокочастотной активности в диапазоне 12-20 Гц.

Состояние концентрации также влияет и на лобные мышцы: чем более сосредоточен человек, тем более расслабленные у него мышцы лба и лица в целом.

Созданное устройство будет считывать основные ритмы ЭЭГ и ЭМГ, и помогать тренировать свою внимательность.

Цель: создать устройство, позволяющее тренировать концентрацию внимания.

Задачи:

1. Изучить теоретические основы физиологии человека.

2. Изучить основы работы с Arduino.

3 Освоить работу с оборудованием ПАК Юниор и RaspberryPi.

4. Разработать схему и собрать устройство.

5. Провести тесты.

Объект исследования: психофизическое состояние человека.

Предмет: Анализ физиологических реакций, регистрируемых в процессе концентрации внимания.

# 1.Теоретическая часть:

# 1.1. Мозг

Картинки по запросу "строение мозга"

Головной мозг человека – орган центральной нервной системы, состоящей из множества взаимосвязанных между собой нервных клеток и их отростков.

Головной мозг человека занимает почти всю полость мозгового отдела черепа, кости которого защищают головной мозг от внешних механических повреждений. B процессе роста и развития головной мозг принимает форму черепа.

Ритмы головного мозга — диагностируемые электрические колебания головного мозга (https://ru.wikipedia.org/wiki/%D0%93%D0%BE%D0%BB%D0%BE%D0%B2%D0%BD%D0%BE%D0%B9_%D0%BC%D0%BE%D0%B7%D0%B3).

В различных состояниях на коре головного мозга человека регистрируются электрические колебания различной амплитуды и частоты. Они были названы ритмами мозга и обозначаются буквами греческого алфавита.

Альфа-волны

Нормальный альфа-ритм на ЭЭГ имеет следующие особенности:

• частота 8-12 Гц: нижний предел нормы альфа-ритма у взрослых и детей старше 8 лет составляет 8 Гц;

• местоположение: затылочные области;

• морфология: ритмичная и регулярная;

• амплитуда: обычно 20-100 мВ;

• реактивность: появляется при закрытии глаз и исчезает при их открытии.

Бета-волны

Нормальный бета-ритм ЭЭГ имеет следующие характеристики:

• Частота (по определению) более 13 Гц.

• Местоположение: диффузное распространение.

• Морфология: обычно ритмичная и симметричная.

• Амплитуда: диапазон 5-20 мВ.

Тета-волны

Медленный ритм в частотном диапазоне от 4 до <8 Гц. Они чаще встречаются во время сонливости и в состояние дрема. Ритмы ЭЭГ и их характеристика зависят от возраста пациента. В состоянии бодрствования они присутствуют у малышей, однако наличие у взрослых может указывать на дисфункцию или поражение головного мозга.

С использованием этих волн связаны и режимы работы нашего устройства.


# 1.2. Мышцы

Лобная мышца (m.frontalis) – поднимает брови и формирует горизонтальные складки лба, когда мы удивляемся.

Фейсбилдинг: упражнения для зоны лба

Основными параметрами поверхностной ЭМГ являются максимальная амплитуда сигнала при измерении ее от пика до пика, средняя амплитуда, средняя частота секундной реализации, средняя амплитуда сигнала. Важным является такой показатель, как амплитудно-частотный коэффициент. До сих пор остается актуальной визуальная оценка рисунка кривых. Ниже на рисунках (Рис. 1.6 — 1.8) представлены типы поверхностной ЭМГ, выделенные Ю.С. Юсевич (1958).

I ТИП ЭМГ характерен для нормальной мышцы и отражает суммарную активность большого числа ДЕ при максимальном сокращении (Рис. 1.6). Частота интерференционной кривой в норме около 50 Гц, амплитуда 1-2 мВ. Выраженное их снижение свидетельствует о выпадении части мышечных волокон из ДЕ и наблюдается при первичных мышечных или аксональных процессах. С дифференциально-диагностическими целями в первом случае целесообразно исследование ПДЕ с помощью игольчатых электродов, во втором - оценка СРВ (скорость распространения возбуждения) и параметров вызванного ответа мышцы и нерва путем стимуляционной ЭМГ.


II ТИП ЭМГ характеризуется относительно редкой ритмической активностью, возникающей в покое. IIа тип имеет частоту 6-200 Гц, амплитуду 50-150 мкВ, IIб тип - 21-50 Гц, 300-500 мкВ (Рис. 1.7). Подтипы IIа и IIб характеризуют степень выраженности патологического процесса, причем IIб свидетельствует о менее грубом поражении мотонейронов и в начальных стадиях заболевания лучше выявляется при тонических пробах.


III ТИП ЭМГ отмечается при супрасегментарных процессах и включает в себя два подтипа: частые ритмические разряды при треморе (Рис. 1.8) и усиление активности покоя при экстрапирамидной ригидности. Гиперкинезы сопровождаются нерегулярными артефактными разрядами, соответствующими насильственным движениям. Параметры СРВ и ПДЕ в этих случаях практически не изменяются, поэтому применение стимуляционной и игольчатой ЭМГ не обязательно.


IV ТИП ЭМГ характеризуется биоэлектрическим молчанием мышцы при попытке произвольного сокращения. Полный паралич может быть связан с острой невропатией, вялой стадией пирамидного паралича, атрофией мышечной ткани различного генеза. Для дифференциальной диагностики уровня поражения показано исследование СРВ по периферическим нервам и анализ параметров ПДЕ с применением игольчатых электродов.

# 1.3 Отслеживание параметров человека

Электроэнцефалограмма (ЭЭГ) — графическое изображение сложного колебательного электрического процесса, который регистрируется при помощи электроэнцефалографа при размещении его электродов на мозге или поверхности скальпа, результат электрической суммации и фильтрации элементарных процессов в нейронах.

# Принцип работы:

Регистрация ЭЭГ производится при помощи электроэнцефалографа через специальные электроды (наиболее распространенные — мостиковые, чашечковые и игольчатые). В настоящее время чаще всего используется расположение электродов по международным системам «10—20 %» или «10—10 %». Каждый электрод подключен к усилителю. Для записи ЭЭГ может использоваться бумажная лента (это устаревший вариант, широко применяемый во времена СССР и РФ вплоть до конца 2000-х годов) или сигнал может преобразовываться с помощью АЦП и записываться в файл на компьютере (современный вариант). Наиболее распространена запись с частотой дискретизации 250 Гц. Запись потенциалов с каждого электрода осуществляется относительно нулевого потенциала референта, за который, как правило, принимается мочка уха или сосцевидный отросток височной кости (processusmastoideus), расположенный позади уха и содержащий заполненные воздухом костные полости.

Система «10—20%» — стандартная система размещения электродов на поверхности головы, которая рекомендована Международной федерацией электроэнцефалографии и клинической нейрофизиологии. Была создана в 1950-х годах канадским нейрофизиологом Гербертом Генри Джаспером.

21 electrodes of International 10-20 system for EEG.svg

Аналого-цифровой преобразователь — устройство, преобразующее входной аналоговый сигнал в дискретный код (цифровой сигнал).

Биологическая обратная связь - технология, включающая в себя комплекс исследовательских, немедицинских, физиологических, профилактических и лечебных процедур, в ходе которых человеку посредством внешней цепи обратной связи, организованной преимущественно с помощью микропроцессорной или компьютерной техники, предъявляется информация о состоянии и изменении тех или иных собственных физиологических процессов.

БОС-процедура заключается в непрерывном мониторинге в режиме реального времени определённых физиологических показателей и сознательном управлении ими с помощью мультимедийных, игровых и других приемов в заданной области значений.

Быстрое преобразование Фурье (англ. Fast Fourier Transform, FFT) — метод, позволяющий вычислять дискретное преобразование Фурье за время O(N²)

Преобразование Фурье (https://ru.wikipedia.org/wiki/%D0%A4%D1%83%D1%80%D1%8C%D0%B5,_%D0%96%D0%B0%D0%BD_%D0%91%D0%B0%D1%82%D0%B8%D1%81%D1%82_%D0%96%D0%BE%D0%B7%D0%B5%D1%84) — операция, сопоставляющая одной функции вещественной переменной другую функцию вещественной переменной.

Электромиография (ЭМГ, ЭНМГ, миография, электронейромиография) — (мио - мышцы и …графо - пишу), метод исследования биоэлектрических (см. Электрофизиология) потенциалов, возникающих в скелетных мышцах человека и животных при возбуждении мышечных волокон; регистрация электрической активности мышц.

# Принцип работы:

После прихода нервного импульса к концевой пластинке (место контакта веточки двигательного нерва и мышцы, рисунок 1 А) происходит деполяризация (в течение 0,5 мс) постсинаптической мембраны мышечного волокна. Деполяризация мембраны мышечных клеток обусловлена движением внутрь ионов Na+ (рисунке 1 Б). Процесс деполяризации распространяется в обе стороны от концевой пластинки со скоростью 2-6 м/c (рисунок 1В). Расположенные в этом поле электроды регистрируют напряжение (электрический потенциал) мышечных волокон. Если электроды расположить вдоль мышечных волокон, то электрический сигнал волокон по форме будет биполярным и знак первой волны будет зависеть от расположения электрода по отношению к волокнам. ЭС волокон с моторными пластинками, расположенными справа от электродов, имеют отрицательный знак, слева – положительный (рисунок 1 Б).
Схематическое представление электромиограммы отдельных двигательных единиц и суммарная миограмма мышцы представлены на рисунке 2.
Амплитуда ЭС зависит от диаметра волокон, расстояния от активированного мышечного волокна, размеров регистрируемой области и фильтрующих свойств электродов. Для тканей человека амплитуда ЭС возрастает пропорционально V=ka1,7, где а радиус мышечного волокна и k — константа. Снижение амплитуды сигнала обратно пропорционально расстоянию до активного волокна и регистрируемой площади. Фильтрующие свойства биполярных электродов зависят от размеров, расстояния между электродами и материала изготовления.

А


Б


B


# 1.4 ПАК «ЮНИор»

  Разрабатываемый программно-аппаратный комплекс “Юный нейроисследователь” (ПАК «ЮНИор») предназначен для обучения школьников и студентов основам нейротехнологий. Он позволяет создавать различные схемы регистрации электрофизиологических сигналов, обрабатывать сигналы, выполнять визуализацию параметров в виде графических образов на ПК, а также управлять посредством электрофизиологических сигналов внешними объектами через плату Arduino. Выполняемый проект ставит основной своей задачей создание инжиниринговой среды системного проектного обучения школьников нейротехнологиям. Данный проект является участником апробации разрабатываемого ПАК ЮНИор и учебно-методического комплекса рекомендаций.

# 1.5 Arduino

  Arduino — это электронный конструктор и удобная платформа быстрой разработки электронных устройств для новичков и профессионалов. Платформа пользуется огромной популярностью во всем мире благодаря удобству и простоте языка программирования, а также открытой архитектуре и программному коду. Устройство программируется через USB без использования программаторов.

Arduino позволяет компьютеру выйти за рамки виртуального мира в физический и взаимодействовать с ним. Устройства на базеArduino могут получать информацию об окружающей среде посредством различных датчиков, а также могут управлять различными исполнительными устройствами.

Микроконтроллер на плате программируется при помощиC++ и среды разработки Arduino (основана на средеWiring). Проекты устройств, основанные на Arduino, могут работать самостоятельно, либо же взаимодействовать с программным обеспечением на компьютере (напр.: Flash, Processing, MaxMSP). Платы могут быть собраны пользователем самостоятельно или куплены в сборе. Программное обеспечение доступно для бесплатного скачивания (http://arduino.cc/en/Main/Software). Исходные чертежи схем (файлы CAD) являются общедоступными, пользователи могут применять их по своему усмотрению.

# 2. Практическая часть
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

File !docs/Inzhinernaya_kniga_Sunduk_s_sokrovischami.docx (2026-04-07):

Муниципальное автономное общеобразовательное учреждение

города Новосибирска

«Гимназия №7 «Сибирская»

Инженерная книга

«Сундук сокровищ»

Авторы работы:

Воробьев Матвей

Чипкин Дмитрий

Игнатович Даниил

контактный телефон:

Руководители:

Бабаева Елена Александровна

Ялышева Анна Владимировна

Новосибирск, 2026

Аннотация проекта

Работа посвящена нейродинамическим процессам регуляции работы ритмов головного мозга , направленного на ежедневную тренировку концентрации внимания. В рамках данного проекта разработано и собрано программируемое биоустройство-тренажер «Сундук сокровищ». Основной идеей устройства является тренинг концентрации внимания за счёт открывания и удерживания расслабленными мышцами лба крышки сундука и нахождении «драгоценных камней» в виде светодиодной ленты при обнаружении датчиком ЭЭГ бета-ритмов.

# Введение

Актуальность

Развитие технологий дает человеку возможности развиваться, решать сложные задачи, но и оказывает негативное влияние на психоэмоциональное состояние людей. Одними из самых распространённых проблем, как среди детей, так и взрослых являются проблемы с концентрацией внимания и рассеянность внимания. Это также связано с различными заболеваниями, например - СДВГ. В наши дни данная проблема является частью науки и активного развития. Столкнувшись с этой проблемой, мы начали искать способы ее решения, что в итоге вылилось в создание нашего устройства, а впоследствии и проекта.

Формирование того или иного психофизиологического состояния связано с активацией/угнетением определённых структур головного мозга. Это сопровождается изменением частотной структуры электроэнцефалограммы – меняется соотношение мощности ритмов ЭЭГ. Так, в состоянии покоя, особенно с закрытыми глазами, наиболее выражен альфа-ритм – активность ЭЭГ в частотном диапазоне 8-12 Гц. При открывании глаз, фокусировке внимания, активном решении каких-либо задач снижается мощность альфа- и повышается мощность бета-ритма – высокочастотной активности в диапазоне 12-20 Гц.

Состояние концентрации также влияет и на лобные мышцы: чем более сосредоточен человек, тем более расслабленные у него мышцы лба и лица в целом.

Созданное устройство будет считывать основные ритмы ЭЭГ и ЭМГ, и помогать тренировать свою внимательность.

Цель: создать устройство, позволяющее тренировать концентрацию внимания.

Задачи:

1. Изучить теоретические основы физиологии человека.

2. Изучить основы работы с Arduino.

3. Разработать схему и собрать устройство.

4. Провести тесты.

Объект исследования: психофизическое состояние человека.

Предмет: Анализ физиологических реакций, регистрируемых в процессе концентрации внимания.
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

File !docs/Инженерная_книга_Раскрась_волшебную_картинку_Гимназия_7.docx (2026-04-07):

муниципальное автономное общеобразовательное учреждение

города Новосибирска

«Гимназия №7 «Сибирская»

Индивидуальный проект

«Раскрась волшебную картинку»

Авторы работы:

Ученик

Рандин Владислав 9 «А»

Руководители: Бабаева Елена Александровна

Ялышева Анна Владимировна

Гурских Владислав Романович

Новосибирск 2025

Введение

Мышцы — органы, состоящие из мышечной ткани; способны сокращаться под влиянием нервных импульсов. Часть опорно-двигательного аппарата. Выполняют различные движения, обеспечивая перемещение тела, поддержание позы, сокращение голосовых связок, дыхание и прочее. Мышечная ткань упруга и эластична; состоит из миоцитов (мышечных клеток). Для мышц характерно утомление, которое проявляется при интенсивной работе или нагрузке.

Релакса́ция (от лат. relaxatio — ослабление, расслабление) — процесс расслабления, сопровождающегося снятием психического напряжения. Релаксация может быть, как непроизвольной, так и произвольной, достигнутой в результате применения специальных психофизиологических техник.
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

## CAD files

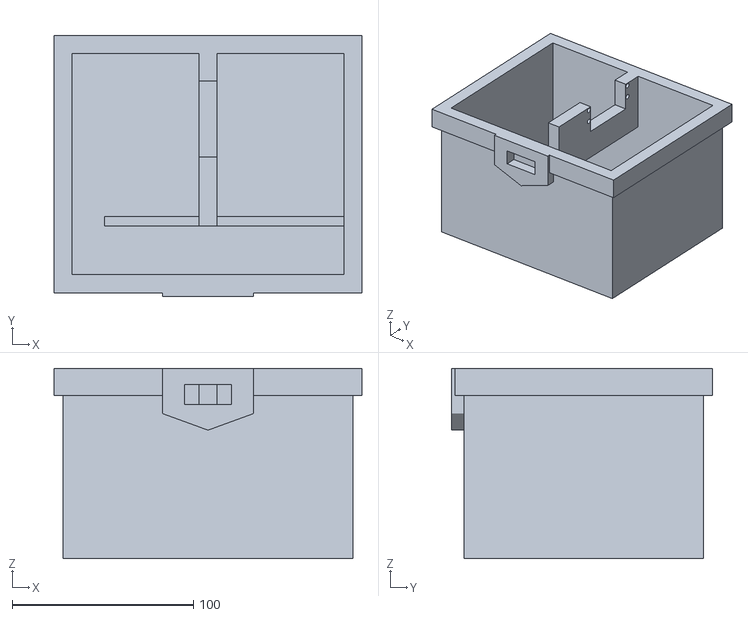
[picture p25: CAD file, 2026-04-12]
src/models/Sunduk_base1.STL
170.0 x 144.0 x 105.0

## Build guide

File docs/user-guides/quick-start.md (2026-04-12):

# 🚀 Быстрый старт - Пошаговое руководство

## Шаг 1: Подготовка оборудования

### Минимальная конфигурация для тестирования (без датчиков):
- Arduino Mega 2560 × 1
- Grove LED Bar v1.0 × 1
- Сервопривод FS5103B × 1
- USB кабель × 1
- Компьютер с Arduino IDE

### Полная конфигурация (с датчиками):
+ Датчик ЭЭГ Bitronics Lab × 1
+ Датчик ЭМГ/ЭКГ Bitronics Lab × 1
+ Электроды для ЭЭГ и ЭМГ
+ Гель для электродов

---

## Шаг 2: Установка ПО

### 1. Установите Arduino IDE
- Скачайте с официального сайта: https://www.arduino.cc/en/software
- Установите согласно инструкции

### 2. Установите библиотеки
В Arduino IDE:
```
Скетч → Подключить библиотеку → Управлять библиотеками...
```

Найдите и установите:
- ✅ **Grove_LED_Bar** от Seeed Studio
- ✅ **arduinoFFT** от Enrique Condes (только для основной версии)

Библиотека **Servo** уже встроена в Arduino IDE.

---

## Шаг 3: Подключение компонентов

### Для тестирования (без датчиков):

1. **Подключите Grove LED Bar:**
   ```
   LED Bar → Arduino Mega
   GND     → GND
   VCC     → 5V
   D1      → Pin 2
   D2      → Pin 3
   ```

2. **Подключите сервопривод:**
   ```
   Серво   → Arduino Mega
   GND     → GND
   VCC     → 5V ⚠️
   SIGNAL  → Pin 9
   ```

⚠️ **ВАЖНО:** Если серво дёргается, используйте отдельное питание 5V 1A!

---

## Шаг 4: Запуск тестовой программы

### 1. Откройте код
В Arduino IDE откройте файл:
```
src/test/treasure_chest_test.ino
```

### 2. Выберите плату
```
Инструменты → Плата → Arduino Mega or Mega 2560
```

### 3. Выберите порт
```
Инструменты → Порт → COM4 (или ваш)
```

### 4. Загрузите код
Нажмите кнопку **Загрузить** (→)

### 5. Откройте Serial Monitor
- Нажмите лупу в правом верхнем углу
- Установите скорость: **115200 бод**

### 6. Проверьте работу
Вы увидите приветственное сообщение. Введите:
```
HELP
```

---

## Шаг 5: Тестирование команд

### Команды управления:

| Команда | Описание |
|---|---|
| `HELP` | Показать справку по командам |
| `STATUS` | Показать текущее состояние системы |
| `AUTO` | Запустить автоматический полный цикл |
| `SUCCESS` | Симуляция успешного выполнения |
| `FAIL_EMG` | Симуляция провала по мышцам |
| `FAIL_EEG` | Симуляция провала по ЭЭГ |
| `RESET` | Перезапустить систему |

### Пример теста:

1. Введите `AUTO` и нажмите Enter
2. Наблюдайте за процессом:
   - Калибровка (30 сек): LED Bar заполняется от 0 до 10
   - Тренинг (3 мин): Серво двигается, LEDs показывают угол
   - Финиш: Результат показывается светодиодами

3. Проверьте статус командой `STATUS`

---

## Шаг 6: Работа с реальными датчиками

### 1. Подключите датчики

**ЭМГ датчик:**
```
ЭМГ модуль → Arduino Mega
GND (-)    → GND
VCC (+)    → 5V
OUT        → A1
```

**ЭЭГ датчик:**
```
ЭЭГ модуль → Arduino Mega
GND (-)    → GND
VCC (+)    → 5V
OUT        → A0
```

### 2. Разместите электроды

**Для ЭМГ (лоб):**
- Электрод 1: над левой бровью (2 см выше)
- Электрод 2: над правой бровью (2 см выше)
- Земля: на виске или за ухом

**Для ЭЭГ:**
- Активный: Fpz (над переносицей, ~10% от переносицы вверх)
- Референт: за ухом (сосцевидный отросток)
- Земля: на лбу справа или слева

### 3. Загрузите основную программу
Откройте и загрузите:
```
src/main/treasure_chest.ino
```

### 4. Откройте Serial Monitor
Установите скорость: **112500 бод**

### 5. Нажмите RESET на Arduino

### 6. Пройдите калибровку (30 секунд)
- Сидите абсолютно спокойно
- Лицо полностью расслаблено
- Глаза открыты, смотрите в одну точку

### 7. Выполните тренинг (3 минуты)
- Расслабьте лоб → крышка открывается
- Решайте простые арифметические задачи → бета-ритм растёт
- Не напрягайте лицо при счёте!

---

## Шаг 7: Оценка результата

### Критерии успеха:

✅ **УСПЕХ (оба условия выполнены):**
- Крышка открыта ≥54° (60% от 90°)
- Бета-ритм > порога ≥60% времени

**Индикация:** Все 10 светодиодов горят, зелёные мигают 5 раз

❌ **НЕУДАЧА:**
- Хотя бы одно условие не выполнено

**Индикация:** Красные светодиоды мигают 3 раза

---

## 🔧 Настройка параметров

Если устройство работает неправильно, измените параметры в коде:

### Если крышка не открывается:
```cpp
const float EMG_THRESHOLD_K = 1.2;  // Было 1.3 (уменьшить)
```

### Если серво дёргается:
```cpp
const unsigned long SERVO_INTERVAL = 300;  // Было 200 (увеличить)
```

### Если трудно достичь успеха:
```cpp
const float BETA_THRESHOLD_K = 0.8;      // Было 0.7 (увеличить)
const float BETA_SUCCESS_RATIO = 0.5;    // Было 0.6 (уменьшить)
```

---

## 🐛 Частые проблемы

| Проблема | Решение |
|---|---|
| Ошибка компиляции | Проверьте, что все библиотеки установлены |
| Серво не двигается | Проверьте подключение, используйте отдельное питание |
| LED Bar не светится | Проверьте подключение D1→2, D2→3 |
| Шум на сигналах | Обезжирьте кожу, используйте гель |
| Всегда неудача | Уменьшите пороги, проведите тренировочные сеансы |

---

## 📞 Дальнейшие шаги

После успешного тестирования:

1. Изучите подробную схему подключения в `docs/hardware/connection-schema.md`
2. Настройте Bitronics Lab для визуализации сигналов
3. Проведите несколько тренировочных сеансов
4. Настройте параметры под конкретного пользователя

---

**УДАЧИ В РЕАЛИЗАЦИИ ПРОЕКТА! 🎉**

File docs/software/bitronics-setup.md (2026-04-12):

# ⚙️ Настройка Bitronics Lab

## Шаг 1: Установка Bitronics Lab

1. Скачайте программу с официального сайта BiTronics
2. Установите согласно инструкции
3. Запустите программу

---

## Шаг 2: Подготовка Arduino

**ВАЖНО:** Перед открытием Bitronics Lab закройте Arduino IDE и Serial Monitor!

1. Загрузите основную программу `src/main/treasure_chest.ino` в Arduino
2. Отключите Arduino от компьютера (или нажмите RESET после подключения)

---

## Шаг 3: Настройка подключения

1. Откройте Bitronics Lab
2. Нажмите **Настройки** (шестерёнка в верхнем меню)
3. В окне настроек выберите:

### Основные настройки:
```
Порт: COM4 (или ваш порт Arduino Mega 2560)
Скорость: 112500 бод
```

### Назначение каналов:
```
КГР порт (ЭМГ): A1
ЭЭГ порт: A0
```

4. Нажмите **Применить**
5. Нажмите **Подключить порт**

---

## Шаг 4: Проверка сигналов

### Вкладка "Визуализатор":

Вы должны увидеть два графика:

**Верхний график (A0 - ЭЭГ):**
- Сигнал мозговой активности
- Амплитуда: обычно 0.5-2В
- Частота: различные ритмы мозга

**Нижний график (A1 - ЭМГ):**
- Сигнал мышечной активности
- В покое: низкий уровень (~0.2-0.5В)
- При напряжении лба: растёт до 1-3В

### Проверка работы:

1. **Проверка ЭМГ:**
   - Прикоснитесь к электродам на лбу
   - Напрягите мышцы лба (нахмурьтесь)
   - График должен показывать рост сигнала

2. **Проверка ЭЭГ:**
   - Сидите спокойно
   - Откройте глаза
   - Решайте простые арифметические задачи (например, 15+27=?)
   - Должен расти бета-ритм (13-18 Гц)

---

## Шаг 5: Настройка регуляторов на модулях

### На модуле ЭЭГ:

**Gain (усиление):**
- Поверните так, чтобы сигнал был 1-2В в активном состоянии
- Если сигнал слишком маленький → увеличьте Gain (по часовой стрелке)
- Если сигнал перегружен (упирается в максимум) → уменьшите Gain

**Noise (подавление шума):**
- Увеличьте, если много помех от сети 50 Гц
- Но не переусердствуйте, чтобы не потерять полезный сигнал

### На модуле ЭМГ:

**Gain (усиление):**
- Для лба: усилить больше (по часовой стрелке)
- Для бицепса: меньше (против часовой)
- Ориентир: в покое ~0.3-0.5В, при напряжении ~2-3В

---

## Шаг 6: Использование триггеров

### Вкладка "ЭМГ":

1. Включите отображение спектра
2. Настройте триггер для детекции напряжения:
   - Порог: установите выше фонового значения
   - При превышении порога → индикатор загорается

### Вкладка "ЭЭГ":

1. Включите отображение спектра
2. Выберите диапазон бета-ритма: 13-18 Гц (для подростков)
   - Или 12-15 Гц (для детей)
3. Настройте триггер для детекции бета-ритма:
   - Порог: установите на уровне 60-70% от максимума

---

## Шаг 7: Калибровка в системе

Во время калибровки (первые 30 секунд после RESET):

1. **Для ЭМГ:**
   - Сидите абсолютно спокойно
   - Лицо полностью расслаблено
   - Не разговаривайте, не глотайте
   - Система запомнит фоновый уровень

2. **Для ЭЭГ:**
   - Глаза открыты
   - Смотрите в одну точку
   - Решайте простые задачи в уме
   - Система запомнит максимум бета-ритма

---

## Шаг 8: Мониторинг во время тренинга

Во время тренинга (3 минуты) наблюдайте:

### В Bitronics Lab:

**Графики в реальном времени:**
- ЭМГ: должен быть низким, когда крышка открывается
- ЭЭГ: бета-ритм должен быть высоким

**Статистика:**
- Процент времени с высоким бета-ритмом
- Текущий угол крышки (если настроено)

### В устройстве:

**LED Bar:**
- Показывает текущий угол крышки (0-10 светодиодов)
- Чем больше горит, тем больше открыто

**Сервопривод:**
- Плавно двигается при изменении ЭМГ
- Открывается, когда расслаблен
- Закрывается, когда напряжён

---

## 🔧 Решение проблем

### Проблема: Нет сигнала в Bitronics Lab

**Причины:**
- Arduino IDE или Serial Monitor открыты
- Неправильный порт выбран
- Неправильная скорость

**Решения:**
1. Закройте все программы, работающие с COM-портом
2. Проверьте порт в Диспетчере устройств Windows
3. Установите скорость 112500 бод

---

### Проблема: Сигнал очень слабый

**Причины:**
- Плохой контакт электродов
- Низкое усиление (Gain)
- Высокий уровень шума (Noise)

**Решения:**
1. Обезжирьте кожу спиртом
2. Используйте гель для электродов
3. Увеличьте Gain на модуле
4. Уменьшите Noise

---

### Проблема: Много помех (50 Гц)

**Причины:**
- Отсутствие заземления
- Близость к источникам помех
- Длинные провода

**Решения:**
1. Убедитесь, что все компоненты имеют общую землю
2. Отодвиньте устройство от монитора, блока питания
3. Укоротите провода электродов
4. Увеличьте Noise на модуле

---

### Проблема: Сигнал перегружен

**Причины:**
- Слишком высокое усиление
- Движения во время измерения

**Решения:**
1. Уменьшите Gain на модуле
2. Попросите испытуемого сидеть спокойнее
3. Лучше зафиксируйте электроды

---

## 📊 Интерпретация результатов

### Нормальные значения:

**ЭМГ (лоб, в покое):**
- Диапазон: 0.2-0.5В
- При напряжении: 1-3В

**ЭЭГ (Fpz, бета-ритм):**
- Фоновый уровень: 0.5-1В
- При концентрации: 1-2В

### Признаки правильной работы:

✅ ЭМГ растёт при напряжении лба
✅ ЭЭГ показывает бета-ритм при решении задач
✅ Крышка открывается при расслаблении
✅ Результат соответствует усилиям испытуемого

---

## 📞 Дополнительные ресурсы

- Официальный сайт BiTronics: http://bitronicslab.com/
- Видеоуроки: https://www.youtube.com/channel/UCGF1CvXMN8c-9aNx3c8tzng
- Мануал "Первые шаги": доступен на сайте BiTronics

---

**УДАЧИ В НАСТРОЙКЕ! 🎉**

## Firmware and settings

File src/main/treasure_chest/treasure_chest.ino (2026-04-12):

#include <fft.h>

/*
 * ============================================================================
 * ПРОЕКТ: "СУНДУК СОКРОВИЩ" - Тренинг биоуправления для коррекции внимания (СДВГ)
 * ============================================================================
 * 
 * ЗАДАЧА:
 * Часть 1: Управление крышкой по ЭМГ (мышцы лба)
 *   - Удерживать ЭМГ ниже порога 3 минуты → крышка открывается (0° → 90°)
 *   - Если ЭМГ выше порога → крышка закрывается в 2 раза быстрее
 *   - Сглаживание ЭМГ скользящим средним (500 мс)
 * 
 * Часть 2: Детекция бета-ритма ЭЭГ (13-18 Гц)
 *   - Если бета-ритм > порога ≥60% времени → зажечь LEDs ("драгоценные камни")
 *   - Периоды с высоким ЭМГ не засчитываются
 * 
 * КАЛИБРОВКА (30 сек):
 *   - Порог ЭМГ: среднее значение в покое × коэффициент 1.3
 *   - Порог ЭЭГ: максимум бета-ритма с открытыми глазами × коэффициент 0.7
 * 
 * ОБОРУДОВАНИЕ:
 *   - Arduino Mega
 *   - Grove LED Bar v1.0 (пины 2, 3) - MY9221
 *   - Сервопривод FS5103B (пин 9)
 *   - Bitronics Lab EEG (A0)
 *   - Bitronics Lab EMG/ECG (A1)
 * 
 * ВЕРСИЯ: 3.0 - Исправлена проблема с дёрганьем серво
 * ============================================================================
 */

#include <Grove_LED_Bar.h>
#include <Servo.h>
#include <arduinoFFT.h>

// ============================================================================
// НАСТРОЙКИ ПИНОВ
// ============================================================================
const int PIN_LED_DATA     = 2;   // Grove LED Bar DATA
const int PIN_LED_CLK      = 3;   // Grove LED Bar CLOCK
const int PIN_SERVO        = 9;   // Сервопривод PWM
const int PIN_EEG          = A0;  // Датчик ЭЭГ Bitronics
const int PIN_EMG          = A1;  // Датчик ЭМГ Bitronics

// ============================================================================
// ТАЙМИНГИ (в миллисекундах)
// ============================================================================
const unsigned long TIME_CALIBRATION    = 30000;  // Калибровка: 30 сек
const unsigned long TIME_TRAINING       = 180000; // Тренинг: 3 минуты
const unsigned long SERVO_INTERVAL      = 200;    // Обновление серво: 200 мс (не чаще!)
const unsigned long SERIAL_INTERVAL     = 30;     // Отправка данных: 30 мс

// ============================================================================
// ПАРАМЕТРЫ БИОУПРАВЛЕНИЯ
// ============================================================================
const float EMG_THRESHOLD_K      = 1.3;   // Коэффициент порога ЭМГ (1.2 = легче)
const float BETA_THRESHOLD_K     = 0.7;   // Коэффициент порога бета-ритма
const float BETA_SUCCESS_RATIO   = 0.6;   // Требуемый % времени с бета-ритмом

// Скорости серво (градусов за обновление 200мс)
const float LID_SPEED_OPEN       = 0.15;  // Медленное открытие
const float LID_SPEED_CLOSE      = 0.30;  // Быстрое закрытие (×2)

// Углы серво
const int SERVO_CLOSED           = 0;     // Закрыто
const int SERVO_OPEN             = 90;    // Открыто
const int LID_SUCCESS_ANGLE      = 54;    // 60% от 90° = 54° (критерий успеха)

// Диапазон бета-ритма (Гц)
const float BETA_FREQ_LOW        = 13.0;  // Для подростков (13-18 Гц)
const float BETA_FREQ_HIGH       = 18.0;
// const float BETA_FREQ_LOW       = 12.0; // Для детей (12-15 Гц)
// const float BETA_FREQ_HIGH      = 15.0;

// ============================================================================
// FFT НАСТРОЙКИ
// ============================================================================
#define FFT_SIZE 64
const float SAMPLING_FREQ = 128.0;  // Частота дискретизации (Гц)

// ============================================================================
// ГЛОБАЛЬНЫЕ ОБЪЕКТЫ
// ============================================================================
Grove_LED_Bar bar(PIN_LED_DATA, PIN_LED_CLK, 1);  // 1 = обратный порядок
Servo servo;
arduinoFFT FFT = arduinoFFT();

// ============================================================================
// СОСТОЯНИЯ СИСТЕМЫ
// ============================================================================
enum State { CALIBRATION, TRAINING, FINISH };
State currentState = CALIBRATION;

// ============================================================================
// ПЕРЕМЕННЫЕ КАЛИБРОВКИ
// ============================================================================
unsigned long phaseStart = 0;
float emgThreshold = 0;
float betaThreshold = 0;
bool isCalibrated = false;

// ============================================================================
// ПЕРЕМЕННЫЕ ЭМГ
// ============================================================================
float emgBuffer[20];         // Буфер на 500 мс (20 × 25 мс)
uint8_t emgIdx = 0;
float emgSmoothed = 0;
bool isRelaxed = true;

// ============================================================================
// ПЕРЕМЕННЫЕ ЭЭГ
// ============================================================================
double eegReal[FFT_SIZE];    // Действительная часть для БПФ
double eegImag[FFT_SIZE];    // Мнимая часть для БПФ
uint8_t eegIdx = 0;

// Статистика бета-ритма
uint16_t betaAboveCnt = 0;   // Счётчик периодов с высоким бета-ритмом
uint16_t validTimeCnt = 0;   // Счётчик валидных периодов (когда расслаблен)

// ============================================================================
// ПЕРЕМЕННЫЕ СЕРВО
// ============================================================================
float lidAngle = 0;
unsigned long lastServoUpdate = 0;

// ============================================================================
// ПЕРЕМЕННЫЕ ДЛЯ ОТПРАВКИ ДАННЫХ
// ============================================================================
unsigned long lastSerialSend = 0;
int rawEMG = 0;
int rawEEG = 0;
float betaPower = 0;

// ============================================================================
// ФУНКЦИЯ: Инициализация оборудования
// ============================================================================
void initHardware() {
  // LED Bar
  bar.begin();
  bar.setLevel(0);
  
  // Серво
  servo.attach(PIN_SERVO);
  servo.write(SERVO_CLOSED);
  lidAngle = SERVO_CLOSED;
  
  // Очистка буферов
  for (uint8_t i = 0; i < 20; i++) emgBuffer[i] = 0;
  for (uint8_t i = 0; i < FFT_SIZE; i++) {
    eegReal[i] = 0;
    eegImag[i] = 0;
  }
}

// ============================================================================
// ФУНКЦИЯ: Чтение сенсора (усреднение 5 отсчётов)
// ============================================================================
int readSensor(int pin) {
  int sum = 0;
  for (uint8_t i = 0; i < 5; i++) {
    sum += analogRead(pin);
    delayMicroseconds(100);
  }
  return sum / 5;
}

// ============================================================================
// ФУНКЦИЯ: Сглаживание ЭМГ (скользящее среднее 500 мс)
// ============================================================================
float smoothEMG(int newValue) {
  emgBuffer[emgIdx] = newValue;
  emgIdx = (emgIdx + 1) % 20;
  
  float sum = 0;
  for (uint8_t i = 0; i < 20; i++) {
    sum += emgBuffer[i];
  }
  return sum / 20.0;
}

// ============================================================================
// ФУНКЦИЯ: Расчёт мощности бета-ритма (БПФ)
// ============================================================================
float calcBetaPower() {
  // Применяем окно Хэмминга
  for (uint8_t i = 0; i < FFT_SIZE; i++) {
    double window = 0.54 - 0.46 * cos(2 * PI * i / (FFT_SIZE - 1));
    eegReal[i] *= window;
    eegImag[i] = 0;
  }
  
  // Прямое БПФ
  FFT.Windowing(eegReal, FFT_SIZE, FFT_WIN_TYP_HAMMING, FFT_FORWARD);
  FFT.Compute(eegReal, eegImag, FFT_SIZE, FFT_FORWARD);
  FFT.ComplexToMagnitude(eegReal, eegImag, FFT_SIZE);
  
  // Находим индексы частот для бета-диапазона
  uint8_t betaLowIdx = (uint8_t)(BETA_FREQ_LOW * FFT_SIZE / SAMPLING_FREQ);
  uint8_t betaHighIdx = (uint8_t)(BETA_FREQ_HIGH * FFT_SIZE / SAMPLING_FREQ);
  
  // Суммируем мощность в бета-диапазоне
  float betaSum = 0;
  float totalSum = 0;
  
  for (uint8_t i = 1; i < FFT_SIZE / 2; i++) {
    totalSum += eegReal[i];
    
    if (i >= betaLowIdx && i <= betaHighIdx) {
      betaSum += eegReal[i];
    }
  }
  
  // Нормализованная мощность бета-ритма
  return (totalSum > 0) ? (betaSum / totalSum) : 0;
}

// ============================================================================
// ФУНКЦИЯ: Обновление положения крышки (вызывается каждые 200 мс)
// ============================================================================
void updateServo() {
  // Проверка уровня ЭМГ
  if (emgSmoothed < emgThreshold) {
    isRelaxed = true;
    // Расслаблен → открываем МЕДЛЕННО
    lidAngle += LID_SPEED_OPEN;
    if (lidAngle > SERVO_OPEN) lidAngle = SERVO_OPEN;
  } else {
    isRelaxed = false;
    // Напряжён → закрываем БЫСТРО (в 2 раза быстрее)
    lidAngle -= LID_SPEED_CLOSE;
    if (lidAngle < SERVO_CLOSED) lidAngle = SERVO_CLOSED;
  }
  
  // Ограничение диапазона
  if (lidAngle < 0) lidAngle = 0;
  if (lidAngle > 90) lidAngle = 90;
  
  // Установка угла серво
  servo.write((int)lidAngle);
  
  // Визуализация на LED Bar (прогресс открытия)
  int level = map((int)lidAngle, 0, 90, 0, 10);
  bar.setLevel(level);
}

// ============================================================================
// ФУНКЦИЯ: Отправка данных на компьютер (для Bitronics Lab)
// ============================================================================
void sendToPC() {
  // Формат: RAW_EEG, RAW_EMG, BETA_POWER, LID_ANGLE, THRESHOLD_FLAG
  Serial.print(rawEEG);
  Serial.print('\t');
  Serial.print(rawEMG);
  Serial.print('\t');
  Serial.print(betaPower, 4);
  Serial.print('\t');
  Serial.print(lidAngle, 1);
  Serial.print('\t');
  Serial.println(isRelaxed ? 1 : 0);
}

// ============================================================================
// СОСТОЯНИЕ: КАЛИБРОВКА (30 секунд)
// ============================================================================
void runCalibration() {
  unsigned long elapsed = millis() - phaseStart;
  
  // Завершение калибровки
  if (elapsed >= TIME_CALIBRATION) {
    isCalibrated = true;
    currentState = TRAINING;
    phaseStart = millis();
    
    // Сигнал успешной калибровки
    bar.setLevel(10);
    delay(300);
    bar.setLevel(0);
    delay(300);
    bar.setLevel(10);
    delay(300);
    bar.setLevel(0);
    
    // Сброс статистики для тренинга
    betaAboveCnt = 0;
    validTimeCnt = 0;
    lidAngle = 0;
    servo.write(SERVO_CLOSED);
    return;
  }
  
  // === РАСЧЁТ ПОРОГА ЭМГ ===
  float smoothed = smoothEMG(rawEMG);
  static float emgSum = 0;
  static uint16_t emgCnt = 0;
  
  emgSum += smoothed;
  emgCnt++;
  
  // Вычисляем порог ЭМГ на середине калибровки
  if (elapsed >= TIME_CALIBRATION / 2 && emgCnt >= 20) {
    emgThreshold = (emgSum / emgCnt) * EMG_THRESHOLD_K;
  }
  
  // === РАСЧЁТ ПОРОГА БЕТА-РИТМА ===
  eegReal[eegIdx] = rawEEG;
  eegIdx = (eegIdx + 1) % FFT_SIZE;
  
  if (eegIdx == 0) {
    float beta = calcBetaPower();
    static float betaMax = 0;
    
    // Запоминаем максимум бета-ритма
    if (beta > betaMax) betaMax = beta;
    betaThreshold = betaMax * BETA_THRESHOLD_K;
  }
  
  // === ВИЗУАЛИЗАЦИЯ ПРОГРЕССА КАЛИБРОВКИ ===
  int level = map(elapsed, 0, TIME_CALIBRATION, 0, 10);
  bar.setLevel(level);
}

// ============================================================================
// СОСТОЯНИЕ: ТРЕНИНГ (3 минуты)
// ============================================================================
void runTraining() {
  unsigned long elapsed = millis() - phaseStart;
  
  // Завершение тренинга
  if (elapsed >= TIME_TRAINING) {
    currentState = FINISH;
    return;
  }
  
  // === ОБРАБОТКА ЭЭГ (каждые 64 отсчёта) ===
  eegReal[eegIdx] = rawEEG;
  eegIdx = (eegIdx + 1) % FFT_SIZE;
  
  if (eegIdx == 0) {
    betaPower = calcBetaPower();
    validTimeCnt++;
    
    // Считаем бета-ритм ТОЛЬКО когда расслаблен
    if (isRelaxed && lidAngle > 10) {
      if (betaPower > betaThreshold) {
        betaAboveCnt++;
      }
    }
  }
  
  // === ОТПРАВКА ДАННЫХ ДЛЯ ВИЗУАЛИЗАЦИИ ===
  Serial.print("#THRESHOLDS\t");
  Serial.print(emgThreshold, 1);
  Serial.print('\t');
  Serial.println(betaThreshold, 4);
}

// ============================================================================
// СОСТОЯНИЕ: ФИНИШ (оценка результата)
// ============================================================================
void runFinish() {
  evaluateResult();
}

// ============================================================================
// ФУНКЦИЯ: Оценка результата
// ============================================================================
void evaluateResult() {
  // Критерий 1: Крышка открыта ≥60% (≥54 градуса)
  bool lidSuccess = (lidAngle >= LID_SUCCESS_ANGLE);
  
  // Критерий 2: Бета-ритм > порога ≥60% времени
  bool betaSuccess = false;
  if (validTimeCnt > 0) {
    float ratio = (float)betaAboveCnt / validTimeCnt;
    betaSuccess = (ratio >= BETA_SUCCESS_RATIO);
    
    // Отладочная информация
    Serial.print("#RESULT\t");
    Serial.print(ratio, 3);
    Serial.print('\t');
    Serial.println(betaSuccess ? "PASS" : "FAIL");
  }
  
  // === ВИЗУАЛИЗАЦИЯ РЕЗУЛЬТАТА ===
  if (lidSuccess && betaSuccess) {
    // ✓ УСПЕХ: зажигаем все светодиоды ("драгоценные камни")
    bar.setLevel(10);
    
    // Мигаем зелёным 5 раз
    for (uint8_t i = 0; i < 5; i++) {
      bar.setBits(0b0000000011);  // Только зелёные
      delay(200);
      bar.setBits(0);
      delay(200);
    }
    bar.setLevel(10);  // Оставляем включенными
  } else {
    // ✗ НЕУДАЧА: мигаем красными
    for (uint8_t i = 0; i < 3; i++) {
      bar.setBits(0b1111111000);  // Только красные
      delay(300);
      bar.setBits(0);
      delay(300);
    }
  }
  
  // Зависаем в этом состоянии
  while (true) {
    delay(1000);
  }
}

// ============================================================================
// SETUP
// ============================================================================
void setup() {
  Serial.begin(112500);  // Скорость для Bitronics Lab
  
  initHardware();
  
  phaseStart = millis();
  
  // Сигнал начала работы
  bar.setLevel(1);
  delay(200);
  bar.setLevel(0);
  delay(200);
  bar.setLevel(1);
}

// ============================================================================
// LOOP
// ============================================================================
void loop() {
  unsigned long currentTime = millis();
  
  // === ЧТЕНИЕ ДАТЧИКОВ (каждый цикл) ===
  rawEMG = readSensor(PIN_EMG);
  rawEEG = readSensor(PIN_EEG);
  
  // === СГЛАЖИВАНИЕ ЭМГ ===
  emgSmoothed = smoothEMG(rawEMG);
  
  // === ОТПРАВКА ДАННЫХ НА ПК (каждые 30 мс) ===
  if (currentTime - lastSerialSend >= SERIAL_INTERVAL) {
    sendToPC();
    lastSerialSend = currentTime;
  }
  
  // === ОБНОВЛЕНИЕ СЕРВО (каждые 200 мс) ===
  if (currentTime - lastServoUpdate >= SERVO_INTERVAL) {
    updateServo();
    lastServoUpdate = currentTime;
  }
  
  // === МАШИНА СОСТОЯНИЙ ===
  switch (currentState) {
    case CALIBRATION:
      runCalibration();
      break;
      
    case TRAINING:
      runTraining();
      break;
      
    case FINISH:
      runFinish();
      break;
  }
  
  // === НЕБОЛЬШАЯ ПАУЗА ДЛЯ СТАБИЛЬНОСТИ АЦП ===
  delay(5);
}

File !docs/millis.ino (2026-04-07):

#include <arduinoFFT.h>
arduinoFFT FFT = arduinoFFT();
#define size 64
#define RED 8
#define GRN 12
#define BLU 13
#include <SoftwareSerial.h>
#include <Servo.h>
Servo mas;
unsigned long last_time_beta_found;
bool beta_found_flag;
SoftwareSerial piSerial(10, 11);

void uniorBegin(/*const int channel, int number_of_channels*/)
{
  piSerial.begin(57600);
  piSerial.write(0xff);
  while (true)
  {
    String s = piSerial.readString();
    if (s == "OK\n")
    {
      String s;
      s += 0;
      s += ";";
      s += 3;
      piSerial.println(s);
      break;
    }
  }
}

bool uniorRead(uint8_t channel_no, float& value)
{
  while (piSerial.available()) piSerial.read();
  piSerial.write(channel_no);
  int readCnt = piSerial.readBytes((byte*)&value, sizeof(float));
  return (readCnt == sizeof(float)) && (value == value);
}

const int cEEG1 = 0;
const int cEMG1 = 3;

double M[64];
double O[64];

void setup() {
  // put your setup code here, to run once:
  last_time_beta_found = millis();
  mas.attach(9);
  mas.write(0);
  Serial.begin(115200);
//  Serial.print("Serial port started with 115200");
  uniorBegin();
  pinMode(RED, OUTPUT);
  pinMode(GRN, OUTPUT);
  pinMode(BLU, OUTPUT);
  for ( int i = 0; i < 64; i++) {
    O[i] = 0;
  }

}


int i = 0;
double mx = M[0];
int u = 0;
void loop() {
  // put your main code here, to run repeatedly:

  float v;
  float w;
  if (uniorRead(cEEG1, v) && uniorRead(cEMG1,w)) //(uniorRead(cEMG1,w)) 
  {
    Serial.print(w);   
    Serial.print('\t');
    Serial.print(beta_found_flag * 1000);
    Serial.print('\t'); 
    Serial.println(v);  

    M[i] = v;
    i++;
    if(w<20 and u==0)
    {
      for(int a=0; a<70; )
      {
        if(millis()-last_time_beta_found>150)
        {
          mas.write(a);
          a+=1;
          // last_time_beta_found=millis();
        }
      }
      u=90;
    }
    else
    {
      if(w>20 and u==90)
      {
        for( int g=70; g!=0; )
        {
          if(millis()-last_time_beta_found>70)
          {
            mas.write(g);
            g-=1;
            // last_time_beta_found=millis();
          }
        }
        u=0;
      }
    }
 
    if(i==64)
    {
      FFT.Compute(M, O, 64, FFT_FORWARD);
      FFT.ComplexToMagnitude(M, O, 64);
      for(int p = 1; p<64; p++)
      {
        if (M[p] > mx)
        {
          mx = M[p];
        }
      }
      beta_found_flag = false;
      for(int e = 16; e<32; e++)
      {
        if(M[e]>= 0.6 * mx)
        {
          beta_found_flag = true;
          break;
        }
      }
      if(beta_found_flag)
      {
        // last_time_beta_found = millis();
        Serial.println("-10000\t-10000\t-10000");
        analogWrite(RED, 0);
        analogWrite(GRN, 255);
        analogWrite(BLU, 150);
        last_time_beta_found = millis();
      }
      else if(millis()-last_time_beta_found > 1300)
      {
        analogWrite(RED, 255);
        analogWrite(GRN, 0);
        analogWrite(BLU, 0);
      }
    
      // for (int x = 0; x < 64; x++) O[x] = 0;
      i = 0;
    }  
  }
  delay(8);
}

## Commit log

2026-04-07 Title: Implementation of Biofeedback Treasure Chest Project with EMG/EEG Control
    Key features implemented:
    - New .gitignore file configured to exclude build artifacts, dependencies, logs, and compressed files
    - Complete Arduino firmware treasure_chest.ino implementing dual biofeedback control system with EMG and EEG sensors
    - Real-time servo control for treasure chest lid based on integrated EMG threshold detection with smoothing algorithm
    - Beta rhythm EEG power analysis using FFT with frequency range configuration for adolescent/child age groups
    - Grove LED Bar visualization showing lid opening progress and success/failure indicators
    - Automatic calibration phase for individual threshold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
    [treasure_chest.ino]
2026-04-07 Title: Add Treasure Chest Biocontrol System with Test Mode and Connection Guide
    - New CONNECTION_GUIDE.md with detailed wiring instructions for Arduino Mega, Grove LED Bar, servo, and EEG/EMG sensors
    - New treasure_chest_test.ino with sensor emulation via serial commands for testing without real hardware
    - Modified .gitignore to properly exclude Arduino build artifacts and dependencies
    - Updated README.md with comprehensive project documentation including wiring diagrams and quick start guide
    - Test mode supports manual/automatic EMG/beta simulation with serial command interface (E/B values, R reset, S status)
    - Implements biocontrol algorithm with smoothed EMG thre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
    [treasure_chest_test.ino]
2026-04-07 в
    в
2026-04-08 Title: Organize neurobiology project with comprehensive documentation and refactored code
    - New hardware connection schema with detailed wiring diagrams for all components
    - Complete Bitronics Lab setup guide with calibration and troubleshooting steps
    - Quick start user guide covering testing without sensors and full deployment
    - Refactored main Arduino code with improved servo control and EMG/EEG processing
    - Test version with sensor emulation and interactive command interface
    - Organized file structure with dedicated docs/src folders and updated gitignore
    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
